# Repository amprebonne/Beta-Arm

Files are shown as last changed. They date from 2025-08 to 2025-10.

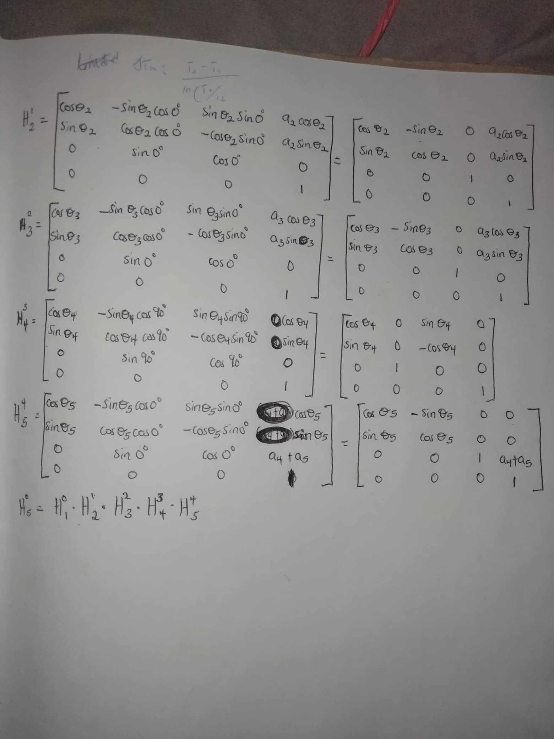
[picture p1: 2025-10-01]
mechanics/kinematics/maths/forward-kinematics-2.jpeg

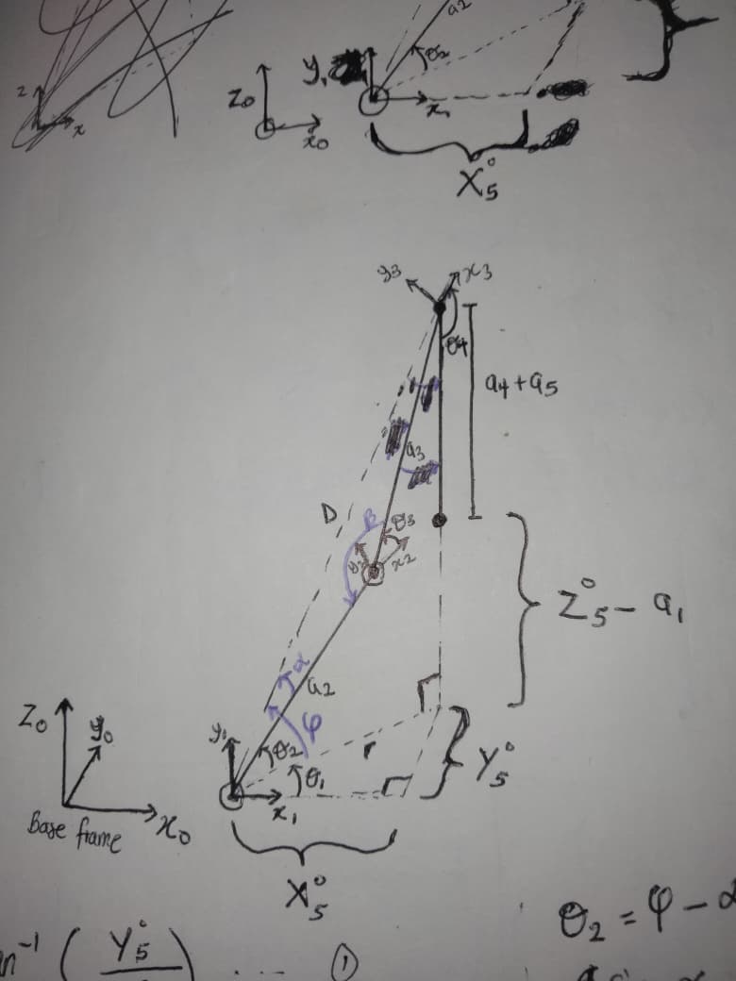
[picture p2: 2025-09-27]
mechanics/kinematics/maths/inverse-kinematics-note-1.jpeg

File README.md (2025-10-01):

# Overview
This repository contains the project files for a capstone project for MTR-362 Robotics, undertaken as part of an undergraduate mechatronics engineering program.
Our project aims to design, build, and demonstrate an intelligent pick-and-place robotic arm. The system integrates machine vision with real-time control to locate, identify, pick, and place selected objects efficiently overcoming the limitations of simple proximity sensor-based robotic arms.

# Objectives:
- Develop a cost-effective robotic arm with a modular design.
- Implement machine vision for precise object detection and localization.
- Achieve real-time multi-axis control using an STM32 microcontroller and G-code interface.
- Demonstrate pick-and-place tasks in a controlled environment.

# Key features
- Custom robotic arm with a gripper end effector.
- An embedded control system featuring an STM32 with Cortex M0 core for motion control.
- A camera module and a host PC for machine vision and object detection providing the MCU with coordinates of object location.

# Appendix: Project Files
This section contains links to all supplementary project files.
- **Project Presentation:** [View the slide deck on Google Slides](https://docs.google.com/presentation/d/1nX-H9TyuoCJQ-igmgSQgIlras0Ow6GI-e8l_YUqkpAM/edit?usp=sharing)
- **Final Project Report:** [Read the complete report](https://www.overleaf.com/3645491839kqrrjfkmpzjt#5574e6)
- **Manipulator kinematic diagrams:** [View the kinematic diagram drawing file](https://docs.google.com/drawings/d/15jNXW8rgt5O_UfLh6RkJmWEusIsC4YRsQ7lwjG3kFDY/edit?usp=sharing)
- **3D CAD Model:** [View the complete robotic arm assembly on Autodesk 3D Viewer](https://autode.sk/4nquLwD)

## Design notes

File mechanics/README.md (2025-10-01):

The robotic manipulator is a 5-DOF articulated arm composed of five revolute joints and corresponding links (\(a_{1}\)–\(a_{5}\)) that form its kinematic chain. Each joint provides a single rotational degree of freedom, enabling coordinated multi-axis motion suitable for basic pick-and-place tasks within a controlled workspace. A gripper end effector is mounted at the terminal link to handle lightweight objects, and the modular structure of the arm allows for easy mechanical adaptation and future extensions.

This directory contains all files related to the mechanical design of the Beta-Arm project. 
Mechanics focuses on the following:
- kinematics modeling & analysis
- mechanical CAD modeling with exports for 3-D printing
- updating the BOM - Bill of Materials with mechanical parts and expenses

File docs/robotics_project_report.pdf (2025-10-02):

# Design and Development of a 5-DOF Pick and Place

Manipulator.

October 2, 2025

## 1 Background

Robotic manipulators are widely used in automation for handling, assembly, and packaging. A 5-DOF arm offers full spatial control, allowing objects to be positioned and oriented flexibly. While industrial robots are effective, they are often costly and complex for small-scale use. Advances in microcontrollers, low-cost actuators, and 3D printing make it possible to build simpler, affordable manipulators. This project applies mechatronics principles to design a functional 6-DOF pick-and-place system as a practical educational prototype.

## 2 Aim

To design and develop a cost-effective 5-DOF robotic arm with a gripper that demonstrates accurate pick-and-place operations using affordable components.

## 3 Objectives

- To design a low-cost 5-DOF robotic arm with modular structure for easy adaptation.
- To implement real-time multi-axis control using an STM32 for precise motion.
- To integrate vision for object detection and demonstrate accurate pick-and-place.

## 4 Scope and Limitations

The project focuses on designing, fabricating, and testing a low-cost 5-DOF manipulator capable of performing basic pick-and-place tasks. The prototype is restricted to light payloads (< 500 g) and operates in a controlled environment with limited accuracy compared to industrial robots.

## 5 System Design Overview

The system consists of a custom-designed 5-DOF robotic arm with a gripper end effector, integrated with an embedded control system based on an STM32 microcontroller (Cortex-M0 core) for precise multi-axis motion. A camera module connected to a host PC provides machine vision capabilities, enabling object detection and localization. The vision system supplies the microcontroller with the coordinates of target objects, which are then used for pick-and-place operations. At the architectural level, the system can be described as a closed-loop mechatronic platform where sensing (camera), computation (PC and STM32), actuation (servo-driven joints), and end-effector manipulation (gripper) interact seamlessly. Functionally, the manipulator executes motion commands derived from G-code instructions while continuously receiving updated position data from the vision system. A block diagram representation of the architecture highlights these subsystems and the flow of information between them.

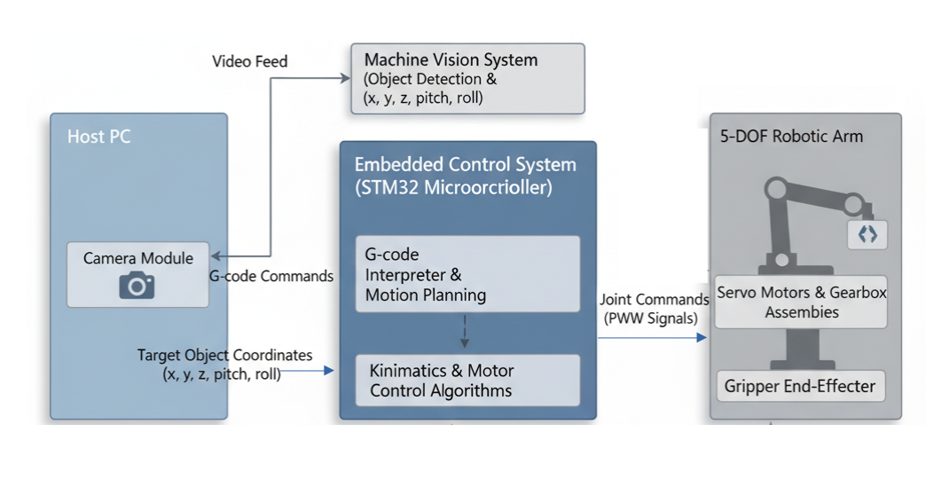
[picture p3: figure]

Figure 1: A block diagram of the Beta-Arm system

## 6 Mechanics

The robotic manipulator is a 5-DOF articulated arm composed of five revolute joints and corresponding links (a1–a5) that form its kinematic chain. Each joint provides a single rotational degree of freedom, enabling coordinated multi-axis motion suitable for basic pick-and-place tasks within a controlled workspace. A gripper end effector is mounted at the terminal link to handle lightweight objects, and the modular structure of the arm allows for easy mechanical adaptation and future extensions.

### 6.1 Kinematics

### 6.1.1 Forward Kinematics

The kinematic model of the manipulator was developed using the defined link lengths (a1–a5) and joint constraints. The structure was modeled in Autodesk Inventor to define geometry and assembly, while MATLAB was used to analyze workspace reach and validate joint limits. The resulting kinematic framework forms the foundation for subsequent motion planning and control.
The forward kinematics of the robotic manipulator involves systematically describing the relation-ship between consecutive links and joints in order to determine the position and orientation of the end-effector relative to the base frame. This process makes use of link parameters, joint definitions, rotational matrices, displacement vectors, and the Denavit–Hartenberg (D–H) convention, culminating in the construction of homogeneous transformation matrices.
1. Link Parameters: Define the physical dimensions of the manipulator, such as link lengths a1–a5, which form the kinematic chain:
a1 = 150.933 mm, | a2 = 128.914 mm, | a3 = 167.164 mm, | a4 = 50.056 mm, | a5 = 75.637 mm
2. Joint Limits: The manipulator consists of five revolute joints, each providing one degree of freedom (DOF). Each joint is constrained within the range:

T0, T1, T2, T3, T4 ∈ [−90◦

, 90◦
]
3. Rotational Matrices: Orientation between consecutive link frames is defined as:
| R
| 0 1 =
1 0 | 0
| 0 0 −1
0 1 | 0
- Ry, | R¹
| | 2 =
0 | 0 1
0 | 1 0
−1 0 0
| | | Rz,

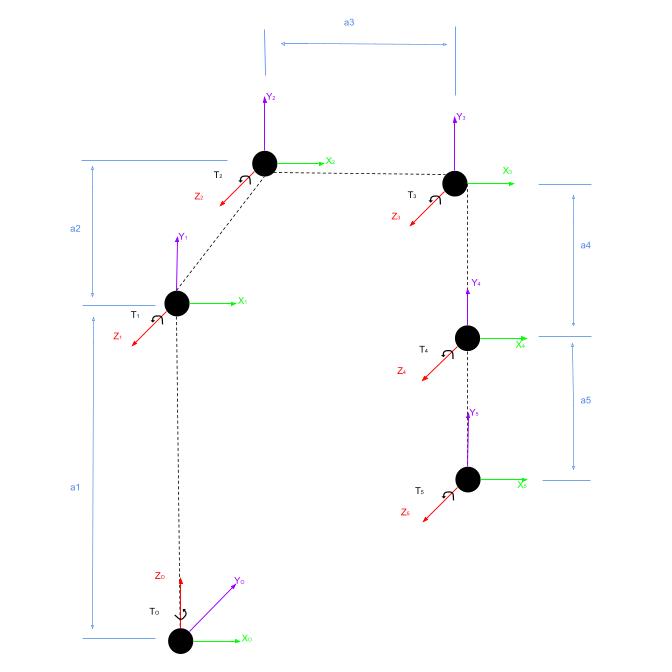
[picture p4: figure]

Figure 2: A kinematic diagram of the 5-DOF manipulator.

R

2
3 =
0 | 0 1
0 | 1 0
−1 0 0
- Rz, R³
4 =

1 0 0
0 0 −1
0 1 0
- Ry

R

4
5 =
1 | 0 | 0
0 | 0 | 1
0 −1 0
- Rz, R⁰
5 =
0 | 0 | 1
0 −1 0
1 | 0 | 0
- Rx
4. Displacement Vectors: Capture the relative translation between link frames, based on link offsets:

d

0
1 =

0
0
a1
- , d¹
2 =

a2
0
0
- , d²
3 =

a3
0
0
- , d³
4 =

a4
0
0
- , d⁴
5 =

0
0
a5
5. Denavit–Hartenberg Parameters in Tabular format: Summarizes all kinematic parameters (θi
, αi

, ai

, di) in a standardized form for the 5-DOF manipulator (see Table 1).

i | θi | αi | ai | di
1 | θ1 | 90◦ | 0 | a1
2 | θ2 | 0 | a2 | 0
3 | θ3 | 0 | a3 | 0
4 | θ4 | 90◦ | 0 | 0
5 | θ5 | 0 | 0 | a4 + a5

Table 1: Denavit–Hartenberg parameters for the robotic arm joints.

6. Homogeneous Transformation Matrices: Combine the rotational and translational effects into a single 4 × 4 matrix, enabling the computation of the end-effector pose by successive multiplications:

ci ≡ cos θi

, | si ≡ sin θi | (i = 1, . . . , 5).

0T1 =

c1 | −s1 cos 90◦
s1 sin 90◦ | 0 · c1
s1 | c1 cos 90◦ | −c1 sin 90◦ | 0 · s1
0 | sin 90◦
cos 90◦ | d1
0 | 0 | 0 | 1

=

c1 | 0 | s1 | 0
s1 | 0 −c1 | 0
0 | 1 | 0 | d1
0 | 0 | 0 | 1

,

where d1 = a1 (per table).

1T2 =

c2 | −s2 cos 0 | s2 sin 0 | a2c2
s2 | c2 cos 0 | −c2 sin 0 a2s2
0 | sin 0 | cos 0 | 0
0 | 0 | 0 | 1

=

c2 | −s2 | 0 a2c2
s2 | c2 | 0 a2s2
0 | 0 | 1 | 0
0 | 0 | 0 | 1

2T3 =

c3 | −s3 cos 0 | s3 sin 0 | a3c3
s3 | c3 cos 0 | −c3 sin 0 a3s3
0 | sin 0 | cos 0 | 0
0 | 0 | 0 | 1

=

c3 | −s3 | 0 a3c3
s3 | c3 | 0 a3s3
0 | 0 | 1 | 0
0 | 0 | 0 | 1

3T4 =

c4 | −s4 cos 90◦
s4 sin 90◦ | 0 · c4
s4 | c4 cos 90◦ | −c4 sin 90◦ | 0 · s4
0 | sin 90◦
cos 90◦ | 0
0 | 0 | 0 | 1

=

c4 | 0 | s4 | 0
s4 | 0 −c4 | 0
0 | 1 | 0 | 0
0 | 0 | 0 | 1

4T5 =

c5 | −s5 cos 0 | s5 sin 0 | 0 · c5
s5 | c5 cos 0 | −c5 sin 0 0 · s5
0 | sin 0 | cos 0 | d5
0 | 0 | 0 | 1

=

c5 | −s5 | 0 | 0
s5 | c5 | 0 | 0
0 | 0 | 1 d5
0 | 0 | 0 | 1

,

where d5 = a4 + a5 (per table).

0T5 =

0T1

1T2

2T3

3T4

4T5

0T5 =

"
R⁵
0 p

5
0
0

⊤ 1

, with R

5

0 = R1R2R3R4R5, p⁵ 0 = (resulting top-right 3×1 block after multiplication).

### 6.1.2 Inverse Kinematics

The inverse kinematics (IK) solution for the given 5-DOF serial manipulator is derived analytically using the Denavit-Hartenberg (DH) parameters. Assume the end-effector pose is specified by the

homogeneous transformation matrix 0T5 =

R p
0

⊤ 1

, where p = [px, py, pz]

⊤ is the position and

R = [rij ] (i, j = 1, 2, 3) is the rotation matrix. The solution proceeds in two stages: (1) solving for the first three joint angles θ1, θ2, θ3 to position the wrist center, and (2) solving for the last two angles θ4, θ5 to achieve the desired orientation. Two solutions may exist due to the elbow singularity (elbow-up/elbow-down configurations).

1. Computing the Wrist Center Position. The wrist center position pw = [pwx, pwy, pwz]

⊤ is
obtained by back-projecting from the end-effector along the approach vector (third column of R):
pwx = px − d5r13, | pwy = py − d5r23, | pwz = pz − d5r33, | (1)

where d5 = a4 + a5.

2. Solving for θ1 (Base Rotation). The first joint angle is determined from the projection in the xy-plane:
| θ1 = atan2(pwy, pwx), | | (2)

where atan2(y, x) is the two-argument arctangent function.
Let c1 = cos θ1 = √ pwx
p²

wx+p²
wy

and s1 = sin θ1 = √ pwy
| p² wx+p² wy .

The radial distance in the xy-plane is xc =

q
| p
| 2 wx + p
| 2 wy.
3. Solving for θ3 (Elbow Angle). Using the law of cosines in the shoulder-elbow-wrist triangle (with vertical offset z

′ = pwz − a1 and planar distance s =

p
| | x
| | 2 c + (z ′) 2):
cos θ3 = | x
| 2 c + (pwz − a1) 2 − a | 2 2 − a
| | 2
| | 3
| 2a2a3 | . | (3)

Then,
sin θ3 = ±

p
1 − cos² θ3, | (4)

yielding two possible solutions (positive for elbow-down, negative for elbow-up).

4. Solving for θ2 (Shoulder Angle). With θ3 known, define A = a2+a3 cos θ3 and B = a3 sin θ3. Then,
θ2 = atan2(z
| ′
, xc) − atan2(B, A), | (5)

where z

′ = pwz − a1.

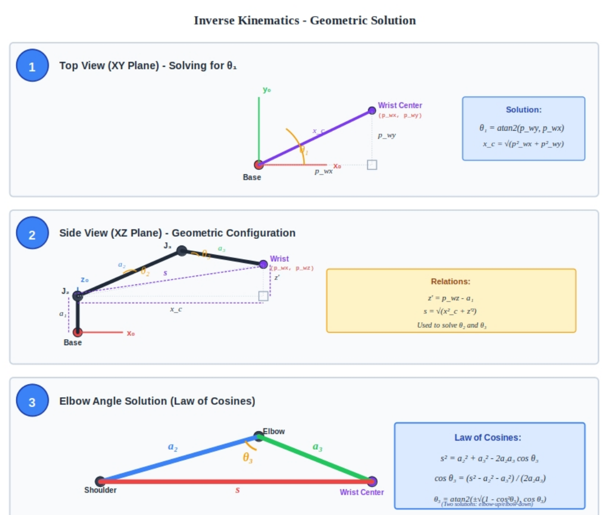
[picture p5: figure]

Figure 3: Inverse kinematic diagrams of the 5-DOF manipulator.

5. Orientation Consistency Check. Computing the columns of 0R3 (rotation matrix to frame
3) using the solved θ1, θ2, θ3:

u =

− sin θ2 sin θ3 cos θ1 + cos θ1 cos θ2 cos θ3 − sin θ1 sin θ2 sin θ3 + sin θ1 cos θ2 cos θ3 sin θ2 cos θ3 + sin θ3 cos θ2

- , v =

− sin θ2 cos θ1 cos θ3 − sin θ3 cos θ1 cos θ2 − sin θ1 sin θ2 cos θ3 − sin θ1 sin θ3 cos θ2 − sin θ2 sin θ3 + cos θ2 cos θ3

(6)
The second column of R must satisfy r·2 = [s1, −c1, 0]⊤ and r32 = 0 for a valid solution; otherwise, no real solution exists.
6. Solving for ϕ = θ4 + θ5 (Wrist Aggregate Angle). Using the third row of R:
ϕ = (θ2 + θ3) − atan2(r31, r33). | (7)
7. Solving for θ4 (Wrist Pitch). The approach vector n = [r13, r23, r33]

⊤ satisfies n = sin θ4 u − cos θ4 v. Thus,
sin θ4 = n
⊤u, | cos θ4 = −n
⊤v, | (8)

and
θ4 = atan2(n

⊤u, −n

⊤v). | (9)
8. Solving for θ5 (Wrist Roll). Finally,
θ5 = ϕ − θ4. | (10)

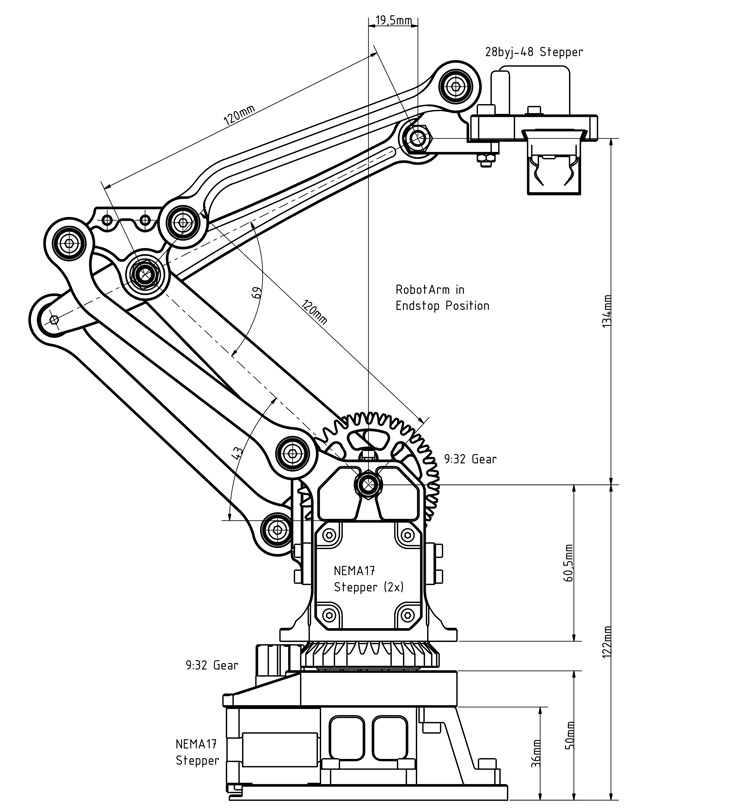
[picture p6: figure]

Figure 4: 2-D CAD drawing

### 6.2 Mechanical-CAD

The mechanical design phase of the Beta-Arm project harnessed Autodesk Inventor as the primary MCAD platform to conceptualize and refine a lightweight, 5-DOF serial robotic arm optimized for 3D printing and servo integration, transforming initial kinematic sketches into a fully assemblable prototype with minimal material waste and enhanced structural performance. The design workflow com-menced in Inventor’s part modeling environment, where over 25 individual components were meticu-lously crafted, including the robust base mount for stable platform attachment, the ergonomic shoulder bracket to distribute torque loads, segmented upper arm links for flexibility, intricate forearm elements to achieve the desired reach, a modular wrist assembly for precise orientation control, and duplicated 29-tooth spur gears to implement backlash-minimizing reduction ratios. Upon finalizing the virtual model, the export phase tailored outputs for downstream manufacturing, generating high-resolution .stl meshes.

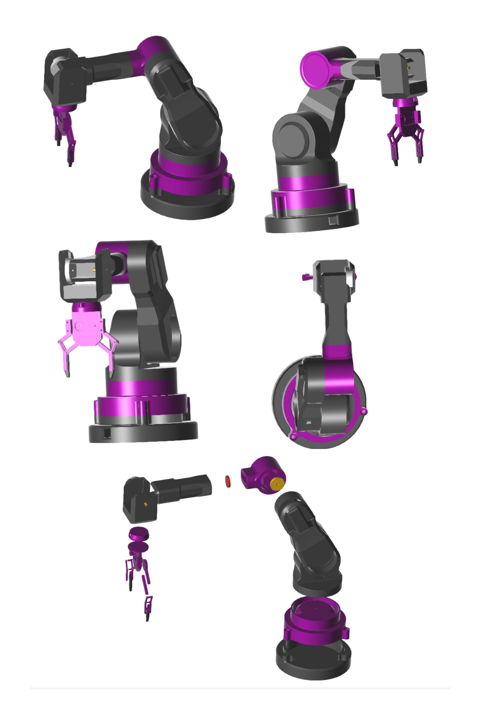
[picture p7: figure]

Figure 5: 3-D projections of the 5-DOF manipulator.

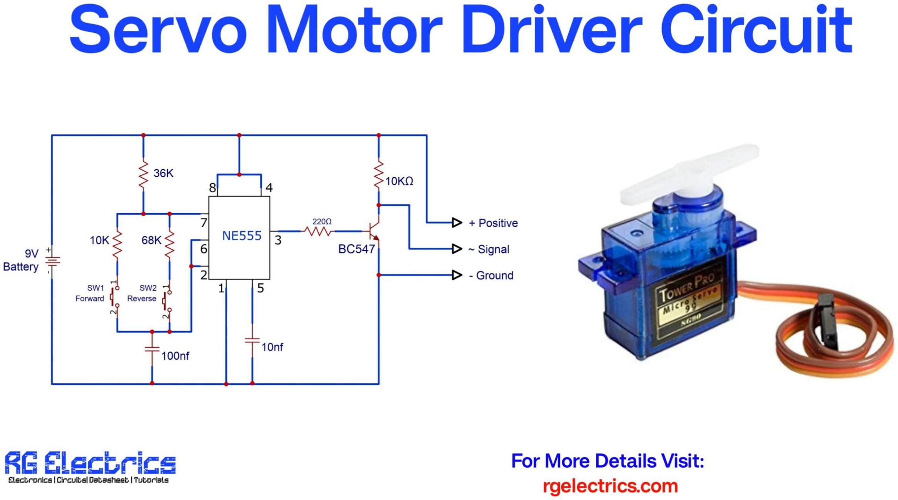
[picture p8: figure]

Figure 6: Circuit schematic

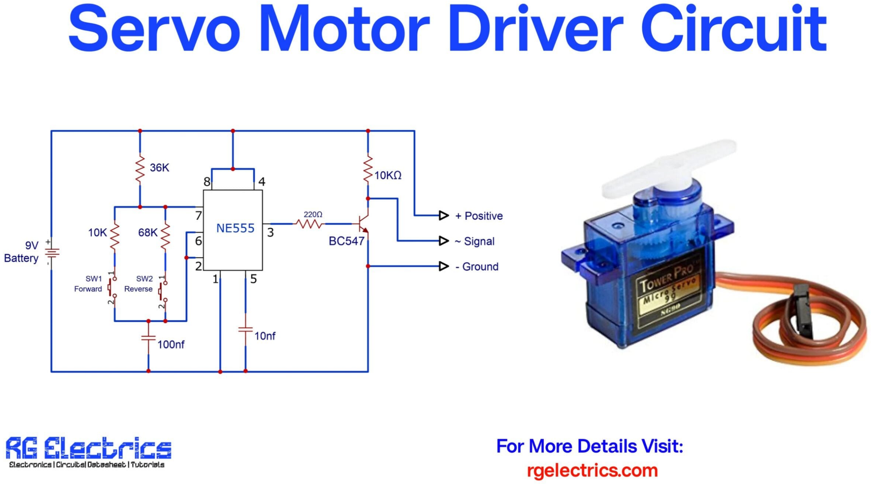
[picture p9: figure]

Figure 7: Circuit schematic

## 7 Electronics

The electronics subsystem of the Beta-Arm integrates low-cost, readily available components to enable precise servo actuation, embedded control, and computer vision integration. Key selections prioritize compatibility with the STM32 microcontroller, power efficiency, and scalability for future enhance-ments like wireless communication.

### 7.1 Circuit Design and Wiring

The circuit employs a modular breadboard layout to minimize soldering and facilitate prototyping. The STM32F030C6 interfaces with the PCA9685 via I²C (SDA/SCL pins) for PWM servo control, with five MG996R servos and one MG90 connected to channels 0–5, sharing a common 5 V rail from the power adapter. UART (TX/RX) on the STM32 links to the host PC for command reception from Python scripts, while the ESP32-CAM connects via USB or serial for image streaming to the host for YOLO processing. Power distribution uses the barrel jack to the breadboard rails.

### 7.2 Bill of Materials (BOM)

The BOM lists essential components, estimated costs, and quantities, totaling under $50 for core electronics.

Component | Qty | Specification
STM32F030C6 | 1 | 32 KB Flash, 4 KB SRAM, 48 MHz, LQFP-48
MG996R Servo | 5 | 11 kg·cm @ 6 V, 4.8–7.2 V, 0.17 s/60°
MG90 Servo | 1 | 2.2 kg·cm @ 4.8 V, 4.8–6 V, 0.1 s/60°
Power Adapter | 1 | 5 V, 3 A output
PCA9685 Driver | 1 | 16-ch PWM, 12-bit, I²C
ESP32-CAM Module | 1 | 1600×1200, Wi-Fi/BT, OV2640
DC Barrel Jack | 1 | 5.5/2.1 mm, 5–12 V
Jumper Cables | Assorted | M-M, M-F, F-F, 10 cm
Mini Breadboard | 1 | 170 tie-points, single rail

Table 2: Bill of Materials for Electronics Subsystem.

## 8 Controls and Software

### 8.1 Embedded Software (STM32F030R6)

The embedded software was developed on the STM32F030R6 microcontroller (ARM Cortex-M0 core) to handle servo actuation and communication with the host PC. The PCA9685 PWM driver was configured over I2C for precise servo control, while UART provided a serial interface for receiving object detection data from the host system.
Key functionalities implemented include:
- System clock configuration at 48 MHz for real-time control.
- I2C initialization for communication with the PCA9685 driver.
- Functions for setting individual, multiple, or all servo angles.
- UART initialization and communication routines for receiving YOLO object detection data.
- Parsing of bounding box coordinates into a format usable for robotic arm control.

Reference: controls-software/Stm32f030rct6/ (GitHub)
[language=C, caption=STM32 Embedded Code Snippet for Servo Control and UART Communication, basicstyle=]
void PCA9685Init(void)
PCA9685W riteReg(P CA9685MODE1, MODE1REST ART);
LLmDelay(10);
uint8tprescale = (uint8t)((OSCF REQ/(4096.0 ∗ SERV OF REQ)) + 0.5) − 1; uint8toldmode = P CA9685ReadReg(P CA9685MODE1);
uint8tnewmode = (oldmode MODE1REST ART)|MODE1SLEEP; PCA9685W riteReg(P CA9685MODE1, newmode);
PCA9685W riteReg(P CA9685P RESCALE, prescale);
PCA9685W riteReg(P CA9685MODE1, oldmode);
LLmDelay(5);
PCA9685W riteReg(P CA9685MODE1, oldmode|MODE1REST ART|MODE1AI); void PCA9685SetServoAngle(uint8tservo, uint16tangledeg)
uint16tpulse = 102 + ((angledeg ∗ 410)/180);
PCA9685SetPWM(servo, 0, pulse);
[language=C, caption=STM32 UART Parsing for YOLO Data, basicstyle=]
void ParseCoordinates(const char* data, int* centerx, int ∗ centery, int ∗ width, int ∗ height) *centerx = ∗centery = ∗width = ∗height = 0; chartempdata[100];
strncpy(tempdata, data, sizeof(tempdata) − 1);
tempdata[sizeof(tempdata) − 1] =′ ′;

char* token = strtok(tempdata, ”, ”); if (token) *centerx = atoi(token); token = strtok(NULL, ",");
if (token) *centery = atoi(token); token = strtok(NULL, ",");
if (token) *width = atoi(token); token = strtok(NULL, ",");
if (token) *height = atoi(token);

### 8.2 Machine Vision

The host PC implements object detection and vision-based control using the YOLOv8 deep learning model. The detected object coordinates (center position and bounding box dimensions) are sent to the STM32 over UART for real-time pick-and-place control.
Key functionalities implemented include:
- Live camera feed acquisition and preprocessing.
- YOLO inference for object detection and localization.
- Real-time visualization of bounding boxes and object centers.
- Serial communication of object coordinates to STM32.

Reference: controls-software/Python Scripts/ (GitHub)
[language=Python, caption=YOLO Object Detection with STM32 Communication, basicstyle=]
model = YOLO(’yolov8n.pt’)
cap = cv2.VideoCapture(1)
cap.set(3, 1280)
cap.set(4, 720)
while True:
success, img = cap.read()
if not success: continue
results = model(img, verbose=False)
for box, cls in zip(results[0].boxes.xyxy.cpu().numpy(), results[0].boxes.cls.cpu().numpy()):
x1, y1, x2, y2 = box.astype(int)
centerx, centery = (x1 + x2)//2,(y1 + y2)//2
width, height = x2 - x1, y2 - y1
cv2.rectangle(img, (x1, y1), (x2, y2), (0,255,0), 2) cv2.circle(img, (centerx, centery), 5,(0, 0, 255), −1) classname = model.names[int(cls)]
cv2.putText(img, classname,(x1, y1 − 10), cv2.FONTHERSHEYSIMP LEX, 0.5,(0, 255, 0), 2) message = f"centerx, centery, width, height˚”

ser.write(message.encode(’utf-8’)) ser.flush()

## 9 Fabrication and Assembly

The manipulator arm was realized through 3D printing of all required links and joints. STL files were first exported and prepared for slicing, after which the parts were printed on an Ender 3 using PLA filament. Once printed, the components were inspected to ensure dimensional accuracy and assembled into the complete manipulator arm without major fitting issues. Parts were assembled without much difficulty.
The manipulator base platform was fabricated from ABS board to provide a stable mounting surface for the arm. A 24 in × 24 in square grid was designed and then pasted onto the ABS board. This ensured accurate placement of the arm and alignment with the workspace. The base platform was successfully made from ABS board and 24×24 inch SAV grid sheets.

The electronic subsystem was developed on a modular breadboard layout to simplify prototyping and reduce soldering. The STM32F030C6 microcontroller interfaced with the PCA9685 driver over I

2C, generating PWM signals for five MG996R servos and one MG90 connected on channels 0–5. All servos shared a regulated 5 V supply distributed across the breadboard rails from a barrel-jack adapter. UART lines on the STM32 were connected to the host PC for command reception from Python scripts, while the ESP32-CAM was connected via USB/serial to provide real-time image streaming for YOLO-based object detection. The integration process involved validating PWM outputs, testing servo response, and checking communication links between the STM32, ESP32-CAM, and PC. The system performed reliably after assembly, with synchronized mechanical actuation and visual feedback confirmed in the gallery records. The circuit was assembled on a breadboard, tested with the PCA9685 and servos, and verified to interface correctly with both the STM32 and ESP32-CAM modules. All subsystems operated as intended.

## 10 Results and Analysis

The manipulator was first subjected to motion tests to verify smooth operation across all joints. Individual servos were actuated and then driven in coordinated sequences to evaluate overall range of motion and responsiveness. These trials confirmed that the PCA9685 driver, controlled through the STM32, produced stable PWM signals that resulted in consistent actuation. Videos of these sequences, including pick-and-place demonstrations, were recorded and archived in the project gallery. Payload capacity was then evaluated by gradually increasing the weight lifted at the gripper. The arm handled lightweight objects reliably, though higher loads highlighted servo torque limitations that constrained the maximum payload which was less than 500 grams.
Accuracy and repeatability were assessed by commanding the manipulator to reach predefined target points on the base platform grid. Measurements showed that the end-effector could consistently reach within a few millimeters of the desired location, with repeat trials producing similar results. However, small deviations were observed due to servo backlash and tolerances in the 3D-printed joints. Overall, the system demonstrated stable motion, adequate payload capacity for its intended use, and reasonable accuracy for an educational and demonstrative robotic manipulator.

## 11 Conclusions and Recommendations

The development of the robotic manipulator successfully demonstrated the integration of embedded control, machine vision, and low-cost fabrication methods. The system achieved smooth joint actuation through the STM32 and PCA9685 driver, with vision-based control enabled by YOLO detection on the host PC. Fabrication using 3D-printed parts and an ABS board platform provided a cost-effective and modular assembly, while circuit prototyping on a breadboard allowed rapid iteration. Motion tests confirmed reliable operation, payload trials showed adequate lifting for lightweight objects, and accuracy tests indicated reasonable repeatability for educational and demonstrative use. Overall, the project achieved its design objectives within the given constraints.
For future improvements, several recommendations are proposed. Mechanical precision can be enhanced by refining 3D-printed joints or introducing metal reinforcements to reduce backlash. Replacing the breadboard layout with a custom PCB would improve reliability and wiring robustness. Higher torque servos or closed-loop actuators could extend payload capacity, while implementing kinematic calibration would improve positioning accuracy. Finally, integrating onboard vision processing directly on an ESP32 or Jetson Nano could reduce latency and enable more autonomous operation. These en-hancements would allow the system to scale from a prototype demonstrator to a more capable robotic platform.

## A Project repository

https://github@@.com/amprebonne/Beta-Arm

## B 3D-MCAD Assembly

https://autode.sk/4nquLwD

## C Gallery

https://github@@.com/amprebonne/Beta-Arm/tree/main/gallery

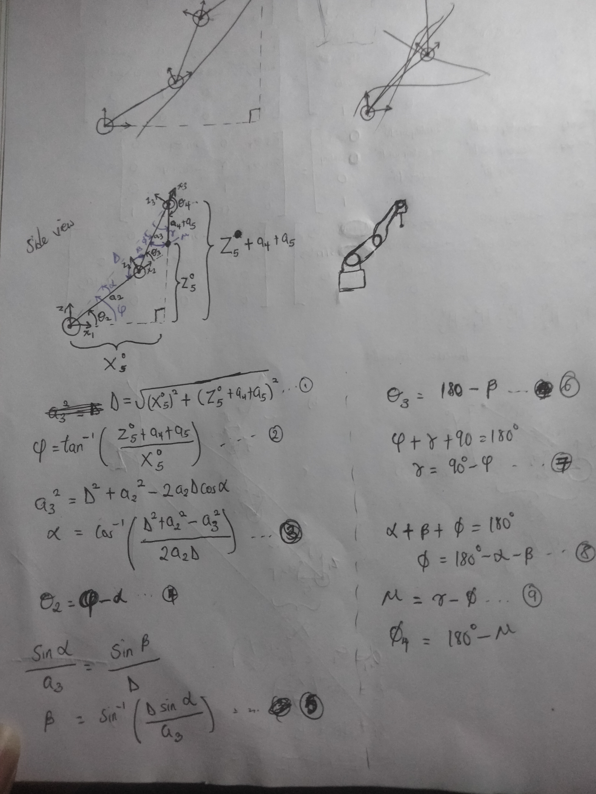
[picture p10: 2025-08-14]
mechanics/kinematics/maths/inverse-kinematics-note-2.jpg

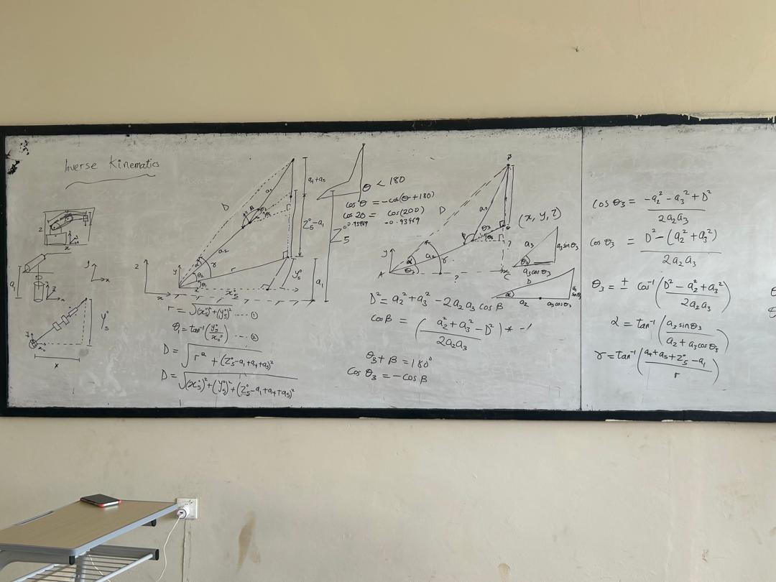
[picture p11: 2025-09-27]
mechanics/kinematics/maths/inverse-kinematics-whiteboarding-2.jpeg

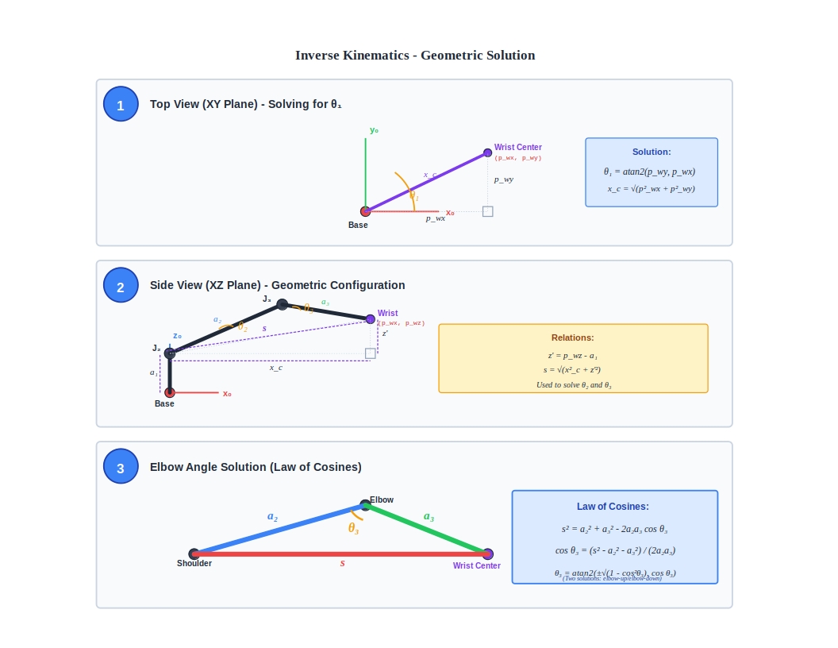
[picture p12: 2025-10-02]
gallery/inverse_kinematics_diagram.jpg

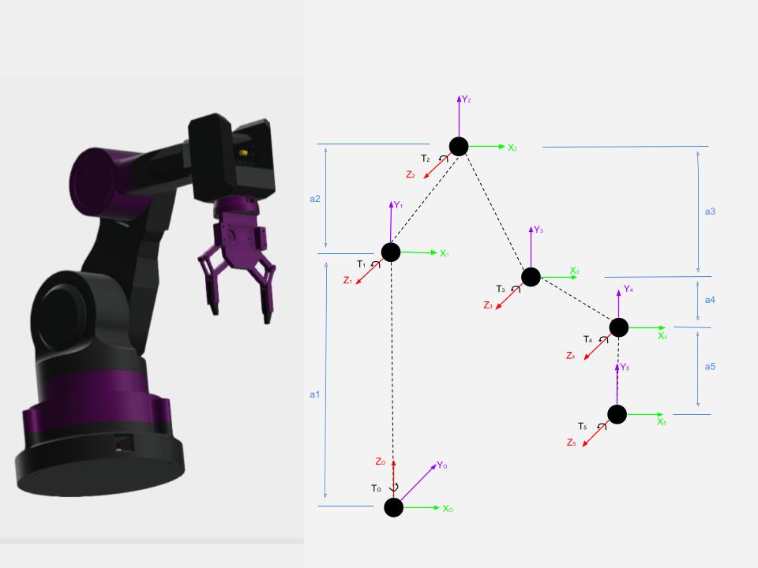
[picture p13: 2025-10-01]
mechanics/kinematics/maths/kinematic-diagram-1.jpg

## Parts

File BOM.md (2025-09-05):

STM32F030C6 → 32 KB Flash, 4 KB SRAM, 48 MHz, LQFP-48

MG996R servos (5) – 11 kg·cm torque @ 6 V, operating voltage 4.8–7.2 V, 0.17 s/60° speed

MG90 servo (1) – 2.2 kg·cm torque @ 4.8 V, operating voltage 4.8–6 V, 0.1 s/60° speed

Power adapter (1) – 5 V, 3 A output

Servo motor driver (1) – 16-channel PWM driver (e.g., PCA9685, 12-bit resolution, I²C interface)

ESP32 camera module (1) – ESP32-CAM, 1600 × 1200 image capture, Wi-Fi + Bluetooth, OV2640 camera sensor

Male power jack supply (1) – DC barrel connector, 5.5 mm outer / 2.1 mm inner diameter, rated 5 V–12 V

Jumper cables – Assorted male-to-male, male-to-female, female-to-female, ~10 cm length

Breadboard (1) – Mini type, ~170 tie-points, single power rail

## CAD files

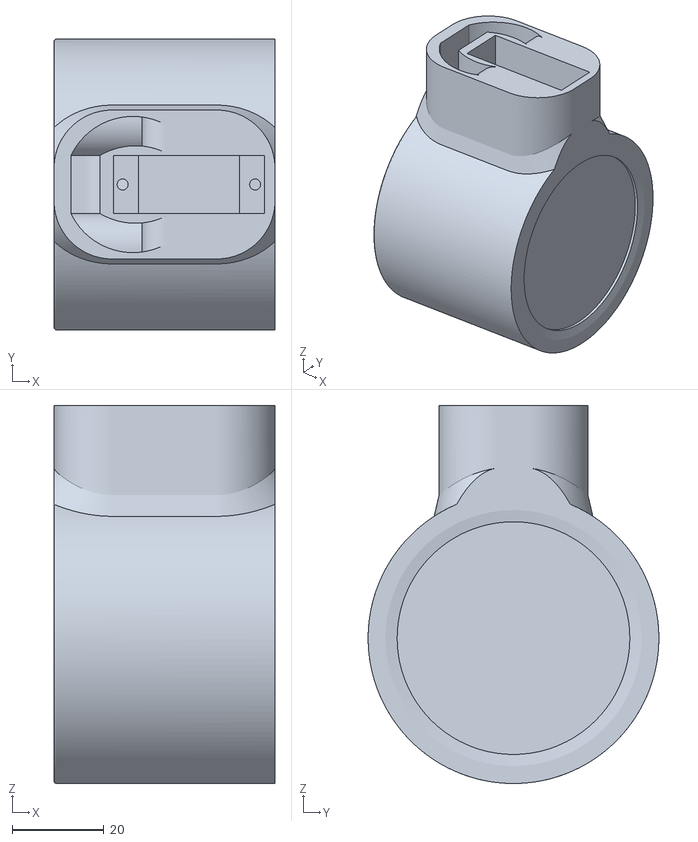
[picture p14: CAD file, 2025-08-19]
fab/arm/3D-printfiles/Assembly 1 - Part 3 - Part 1.stl
48.3 x 63.5 x 82.6

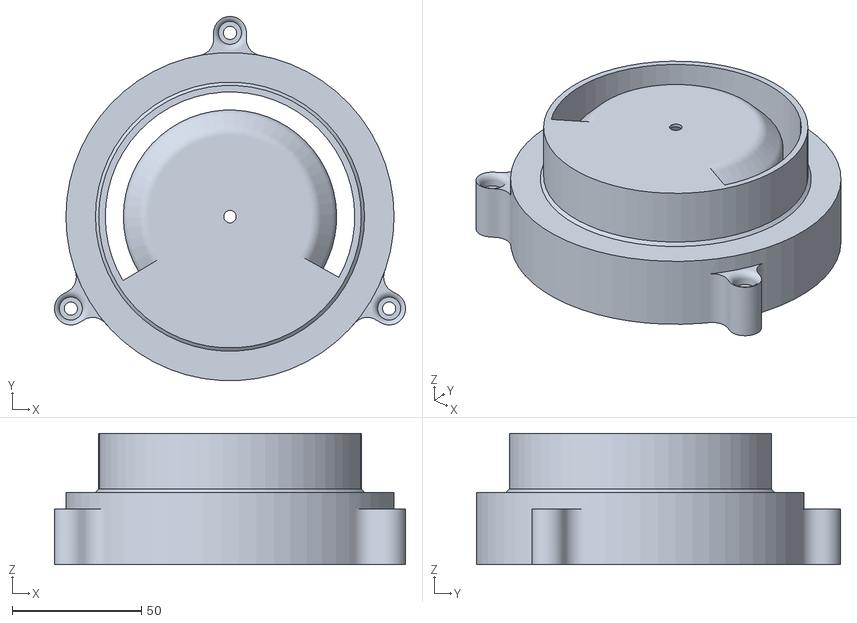
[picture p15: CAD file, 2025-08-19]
fab/arm/3D-printfiles/Assembly 1 - Part 1 - Part 1.stl
135.9 x 140.9 x 50.8

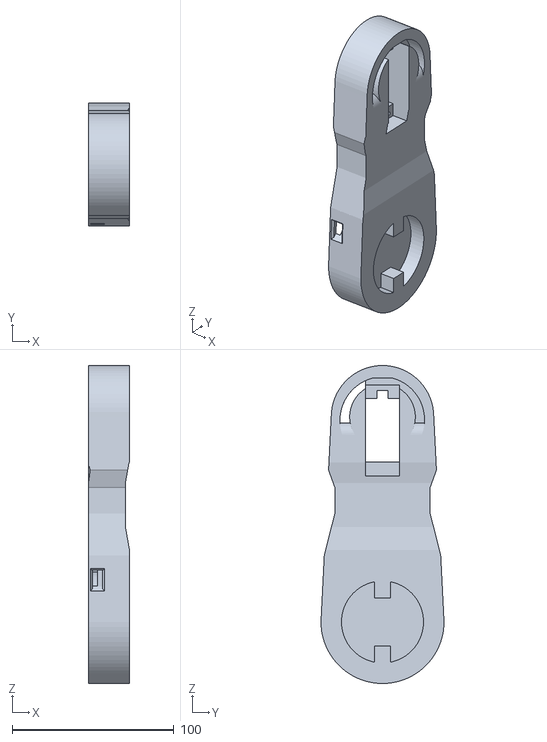
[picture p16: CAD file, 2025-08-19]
fab/arm/3D-printfiles/Assembly 1 - Part 10.stl
25.4 x 76.2 x 196.9

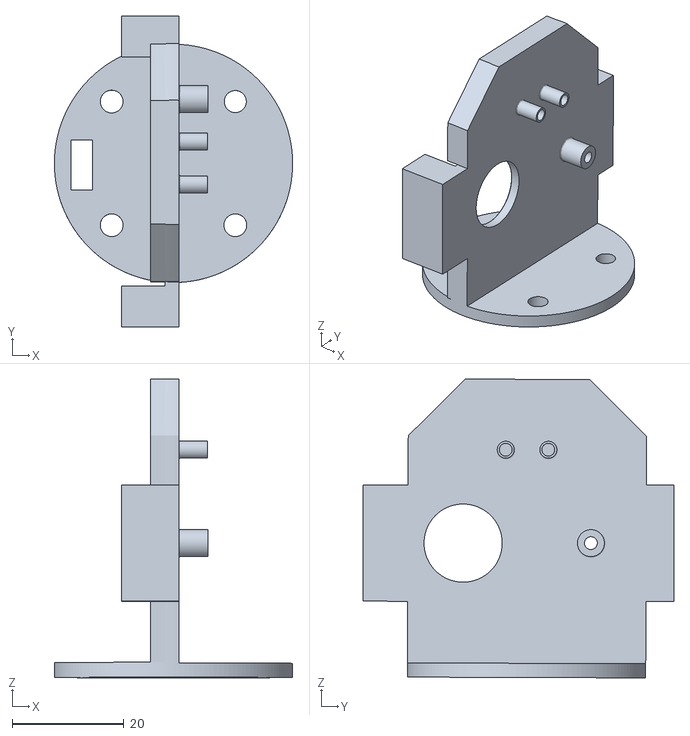
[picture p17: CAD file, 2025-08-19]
fab/arm/3D-printfiles/Assembly 1 - Part 52 - Part 1.stl
42.6 x 55.6 x 53.5

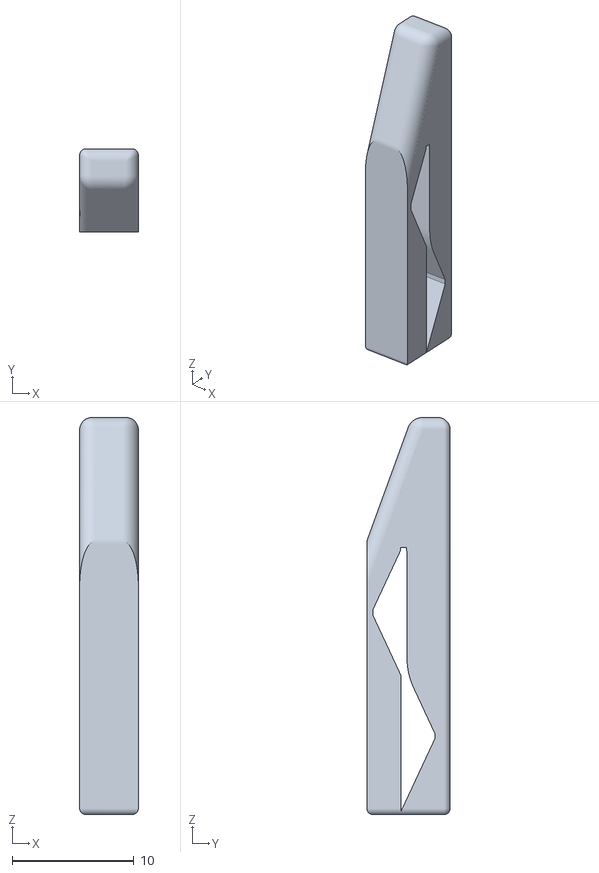
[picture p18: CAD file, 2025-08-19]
fab/arm/3D-printfiles/Assembly 1 - Part 62 - Part 1.stl
4.83 x 6.86 x 32.6

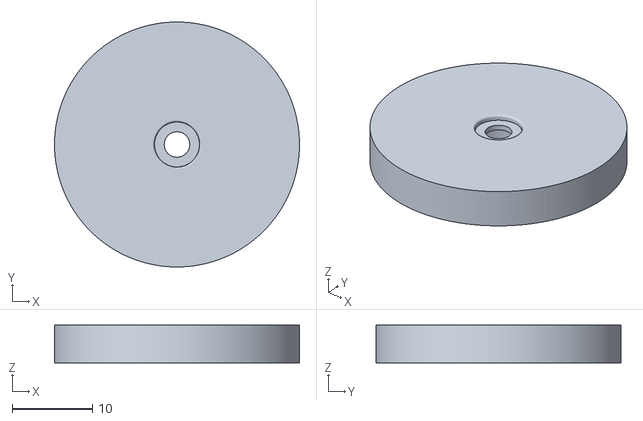
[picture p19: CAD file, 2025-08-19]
fab/arm/3D-printfiles/Assembly 1 - Part 15 - Part 1.stl
30.5 x 30.5 x 4.70

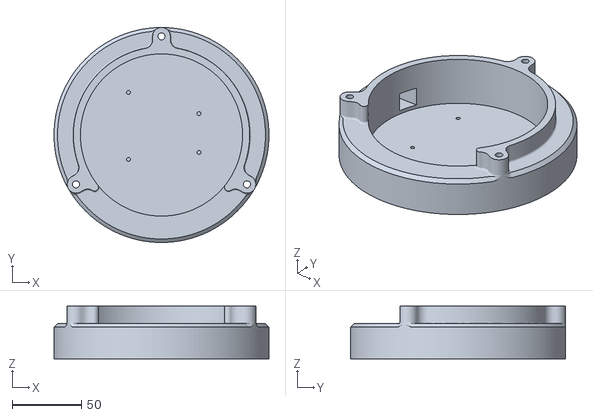
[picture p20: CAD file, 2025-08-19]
fab/arm/3D-printfiles/Assembly 1 - Part 18 - Part 1.stl
154.9 x 154.9 x 38.1

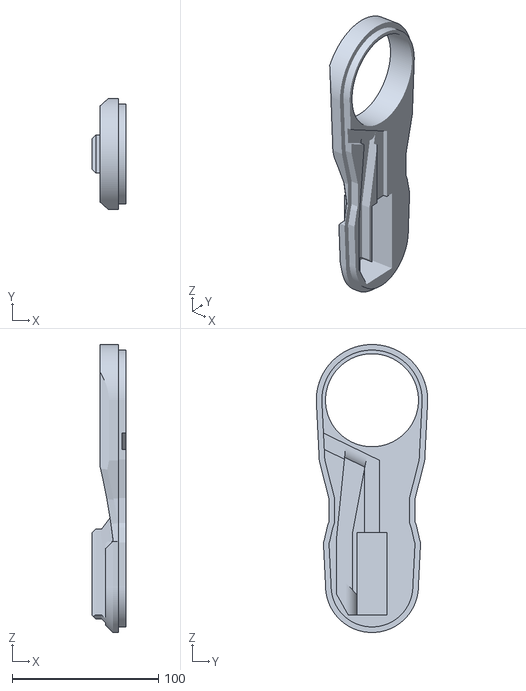
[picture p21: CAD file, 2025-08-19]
fab/arm/3D-printfiles/Assembly 1 - Part 11_MIR - Part 1.stl
23.0 x 76.2 x 196.8

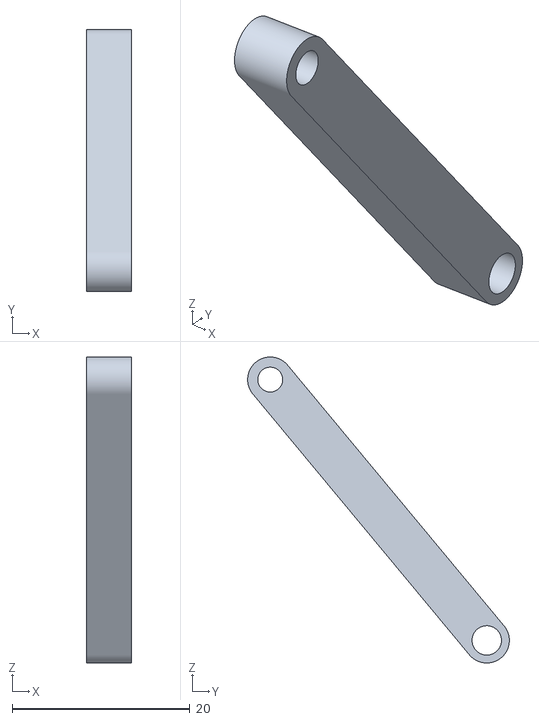
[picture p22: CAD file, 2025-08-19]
fab/arm/3D-printfiles/Assembly 1 - Part 56 - Part 1.stl
5.08 x 29.4 x 34.4

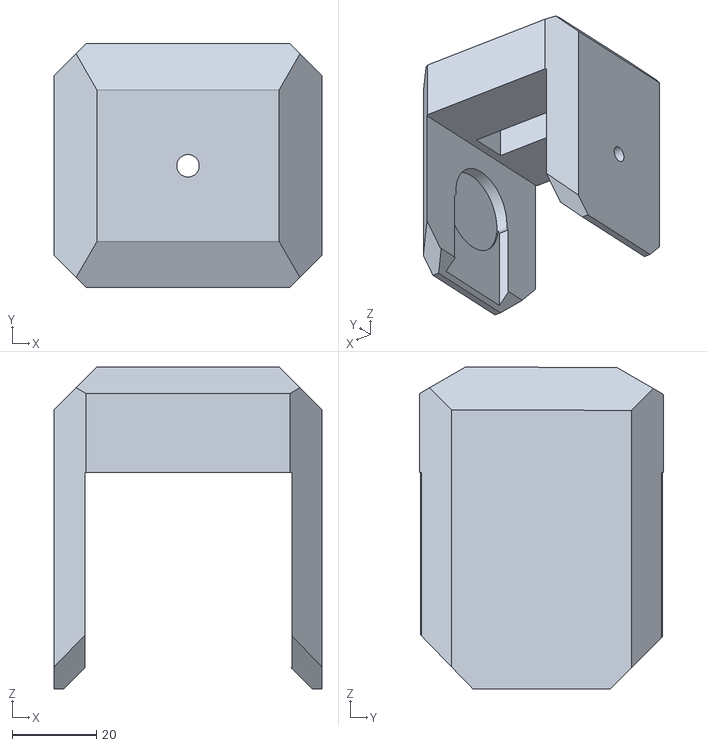
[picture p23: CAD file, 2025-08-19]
fab/arm/3D-printfiles/Assembly 1 - Part 6 - Part 1.stl
63.5 x 57.9 x 76.4

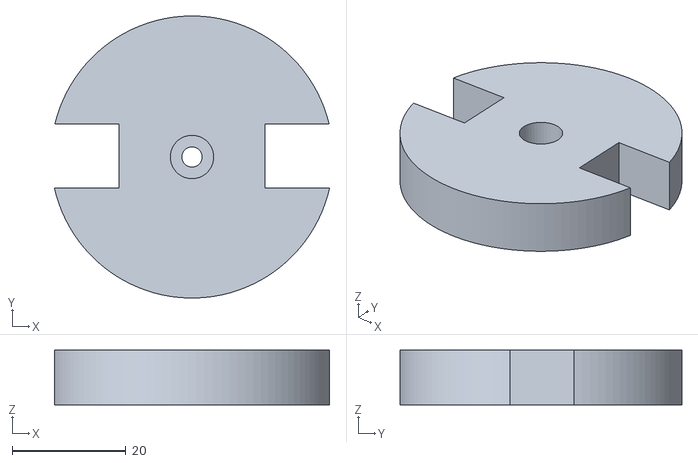
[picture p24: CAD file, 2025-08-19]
fab/arm/3D-printfiles/Assembly 1 - Part 16.stl
48.3 x 49.5 x 9.65

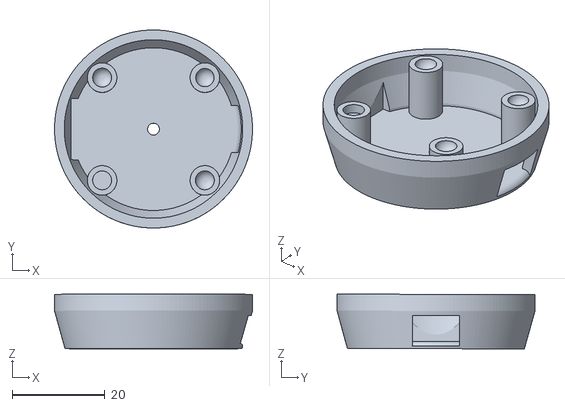
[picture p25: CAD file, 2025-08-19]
fab/arm/3D-printfiles/Assembly 1 - Part 14 - Part 1.stl
42.6 x 42.6 x 11.8

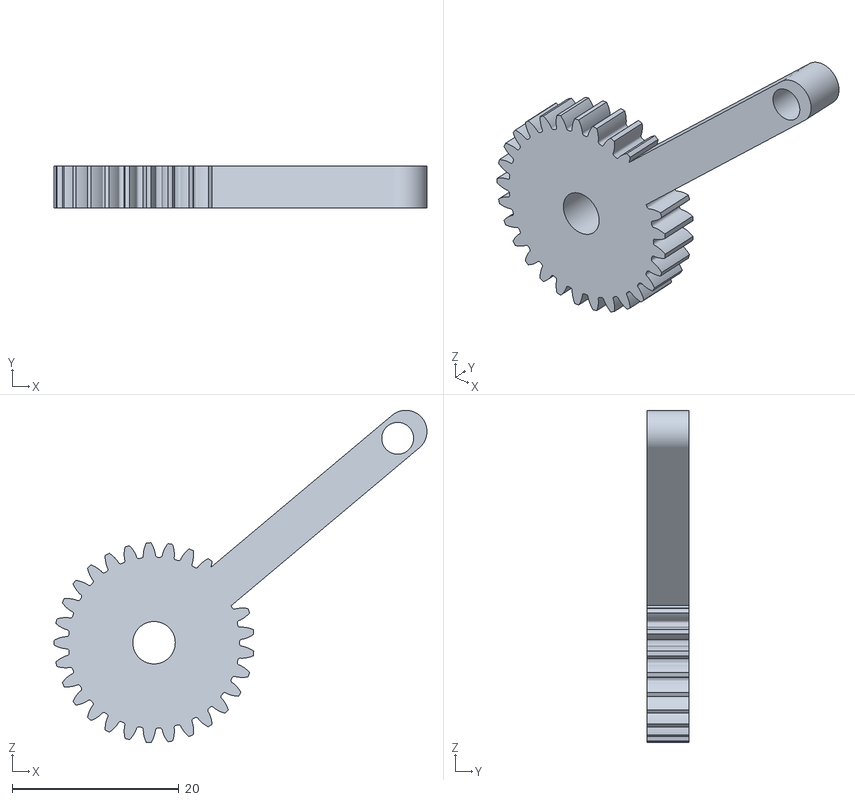
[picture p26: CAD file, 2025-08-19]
fab/arm/3D-printfiles/Assembly 1 - Spur gear (29 teeth) (1) - Part 1.stl
44.7 x 5.08 x 39.8

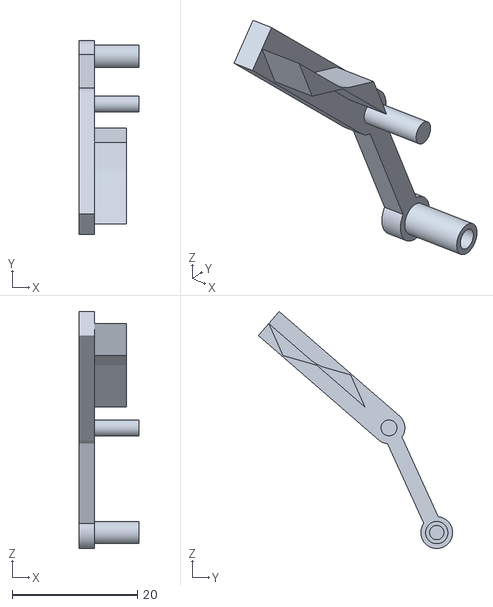
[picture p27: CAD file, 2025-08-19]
fab/arm/3D-printfiles/Assembly 1 - Part 57 - Part 1.stl
9.65 x 31.0 x 37.8

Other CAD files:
fab/arm/3D-printfiles/Assembly 1 - Part 55 - Part 1.stl
fab/arm/3D-printfiles/Assembly 1 - Part 19.stl
fab/arm/3D-printfiles/Assembly 1 - Part 2.stl
fab/arm/3D-printfiles/Assembly 1 - Part 58 - Part 1.stl
fab/arm/3D-printfiles/Assembly 1 - Part 4 - Part 1.stl
fab/arm/3D-printfiles/Assembly 1 - Part 59 - Part 1.stl
fab/arm/3D-printfiles/Assembly 1 - Part 6 (1) - Part 1.stl
fab/arm/3D-printfiles/Assembly 1 - Part 61 - Part 1.stl
fab/arm/3D-printfiles/Assembly 1 - Part 63 - Part 1.stl
fab/arm/3D-printfiles/Assembly 1 - Spur gear (29 teeth) - Part 1.stl
mechanics/CAD/inventor-exports/Assembly 1 - Part 1/Assembly 1 - Part 1.ipt
mechanics/CAD/inventor-exports/Assembly 1 - Part 1/OldVersions/Assembly 1 - Part 1.0002.ipt
mechanics/CAD/inventor-exports/Assembly 1 - Part 10/Assembly 1 - Part 10.ipt
mechanics/CAD/inventor-exports/Assembly 1 - Part 10/OldVersions/Assembly 1 - Part 10.0001.ipt
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

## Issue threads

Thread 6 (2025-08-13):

Fabrication - 3D printing

AurelixML, 2025-08-13:
**Task:**
- Export .stl files for printing
- Ensure all parts are 3D printed and functional.

**Deliverables:**
- Upload .stl files to Beta-Arm/fab/printfiles
- Upload image of each printed part to Beta-Arm/fab/3D-prints

Closed 2025-09-05.

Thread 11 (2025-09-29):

base platform

amprebonne, 2025-09-29:
Task:
- Make platform base from wood, perspex, PVC or ABS board material.
- Design grid and export printables in pdf format.
- Print grid sheet and paste on wooden base surface.

Deliverables:
- Base grid printfile - /fab/platform
- Base grid fabrication assembly - /gallery

Closed 2025-09-29.

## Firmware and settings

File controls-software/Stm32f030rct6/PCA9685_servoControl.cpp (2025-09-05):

#include "stm32f0xx_ll_rcc.h"
#include "stm32f0xx_ll_system.h"
#include "stm32f0xx_ll_utils.h"
#include "stm32f0xx_ll_gpio.h"
#include "stm32f0xx_ll_i2c.h"
#include "stm32f0xx_ll_bus.h"



// PCA9685 Register Addresses
#define PCA9685_MODE1       0x00
#define PCA9685_PRESCALE    0xFE
#define PCA9685_LED0_ON_L   0x06
#define PCA9685_LED0_ON_H   0x07
#define PCA9685_LED0_OFF_L  0x08
#define PCA9685_LED0_OFF_H  0x09

// PCA9685 Mode bits
#define MODE1_RESTART       0x80
#define MODE1_SLEEP         0x10
#define MODE1_AI            0x20

// Configuration
#define PCA9685_I2C_ADDR    0x40        // 7-bit address
#define SERVO_FREQ          50          // 50Hz for standard servos
#define OSC_FREQ            25000000    // Internal oscillator frequency

// Function prototypes
void SystemClock_Config(void);
void I2C1_Init(void);
void PCA9685_Init(void);
void PCA9685_SetServoAngle(uint8_t servo, uint16_t angle_deg);
void PCA9685_SetAllServos(uint16_t angle_deg);
void PCA9685_SetMultipleServos(uint16_t angles[6]);
void PCA9685_SetPWM(uint8_t servo, uint16_t on, uint16_t off);
void PCA9685_WriteReg(uint8_t reg, uint8_t value);
uint8_t PCA9685_ReadReg(uint8_t reg);

int main(void)
 {
    SystemClock_Config();
     LL_Init1msTick(48000000);
    I2C1_Init();
    
    // Initialize PCA9685
    PCA9685_Init();
    
    
    while (1)
    {
        
    //    while(1){
    //    for (float angle = 100; angle <= 180; angle +=10) {
    //    PCA9685_SetServoAngle(0, angle);
    //    LL_mDelay(100); // Wait 500ms between steps - using wait_ms() for your library
    //    // wait_ms(500); // Alternative using your library's wait_ms function
    //  }
    
    //for (float angle = 180; angle >= 100; angle -= 10) {
    //    PCA9685_SetServoAngle(0, angle);
    //    LL_mDelay(100);
    //}
    //LL_mDelay(5000);
    //}
        //PCA9685_SetServoAngle(0, 150);  // Move servo to 90°
        LL_mDelay(300000);  // Stagger the movement
        // Example 1: Control all 6 servos to same position
        PCA9685_SetAllServos(0);    // All to 0°
        LL_mDelay(1000);
        
        
        // Example 2: Control each servo individually
        for(uint8_t servo = 0; servo < 6; servo++)
        {
            PCA9685_SetServoAngle(servo, 90);  // Move servo to 90°
            LL_mDelay(300);  // Stagger the movement
        }
        LL_mDelay(1000);
        
        // Example 3: Set all servos to different positions at once
        uint16_t positions[6] = {0, 30, 60, 90, 120, 180};  // Different angles
        PCA9685_SetMultipleServos(positions);
        LL_mDelay(2000);
        
        // Example 4: Wave pattern
        for(uint16_t angle = 0; angle <= 180; angle += 10)
        {
            for(uint8_t servo = 0; servo < 6; servo++)
            {
                uint16_t servo_angle = angle + (servo * 15);  // Offset each servo
                if(servo_angle > 180) servo_angle = 180;
                PCA9685_SetServoAngle(servo, servo_angle);
            }
            LL_mDelay(100);
        }
        
        LL_mDelay(2000);
    }
}

void PCA9685_Init(void)
{
    // Reset the PCA9685
    PCA9685_WriteReg(PCA9685_MODE1, MODE1_RESTART);
    LL_mDelay(10);
    
    // Set PWM frequency to 50Hz for servo control
    // Calculate prescale: prescale = (OSC_FREQ / (4096 * freq)) - 1
    uint8_t prescale = (uint8_t)((OSC_FREQ / (4096.0 * SERVO_FREQ)) + 0.5) - 1;
    
    // Put PCA9685 to sleep to set prescale
    uint8_t oldmode = PCA9685_ReadReg(PCA9685_MODE1);
    uint8_t newmode = (oldmode & ~MODE1_RESTART) | MODE1_SLEEP;
    PCA9685_WriteReg(PCA9685_MODE1, newmode);
    
    // Set prescale
    PCA9685_WriteReg(PCA9685_PRESCALE, prescale);
    
    // Wake up and enable auto-increment
    PCA9685_WriteReg(PCA9685_MODE1, oldmode);
    LL_mDelay(5);
    PCA9685_WriteReg(PCA9685_MODE1, oldmode | MODE1_RESTART | MODE1_AI);
}

void PCA9685_SetServoAngle(uint8_t servo, uint16_t angle_deg)
{
    // MG996R extended range: 1ms to 2.5ms for 0° to 180°
    // At 50Hz: 20ms period = 4096 counts
    // 1ms = 204.8 counts ≈ 205
    // 2.5ms = 512 counts
    uint16_t pulse = 102 + ((angle_deg * 410) / 180);  // 0.5ms to 2.5ms range
    
    PCA9685_SetPWM(servo, 0, pulse);
}

void PCA9685_SetPWM(uint8_t servo, uint16_t on, uint16_t off)
{
    uint8_t reg = PCA9685_LED0_ON_L + 4 * servo;
    
    PCA9685_WriteReg(reg,     on & 0xFF);        // ON_L
    PCA9685_WriteReg(reg + 1, on >> 8);          // ON_H
    PCA9685_WriteReg(reg + 2, off & 0xFF);       // OFF_L
    PCA9685_WriteReg(reg + 3, off >> 8);         // OFF_H
}

void PCA9685_WriteReg(uint8_t reg, uint8_t value)
{
    // Wait until I2C is ready
    while(LL_I2C_IsActiveFlag_BUSY(I2C1));
    
    // Start I2C transaction
    LL_I2C_HandleTransfer(I2C1, PCA9685_I2C_ADDR << 1, LL_I2C_ADDRSLAVE_7BIT, 2, 
                         LL_I2C_MODE_AUTOEND, LL_I2C_GENERATE_START_WRITE);
    
    // Send register address
    while(!LL_I2C_IsActiveFlag_TXIS(I2C1));
    LL_I2C_TransmitData8(I2C1, reg);
    
    // Send data
    while(!LL_I2C_IsActiveFlag_TXIS(I2C1));
    LL_I2C_TransmitData8(I2C1, value);
    
    // Wait for transfer complete
    while(!LL_I2C_IsActiveFlag_STOP(I2C1));
    LL_I2C_ClearFlag_STOP(I2C1);
}

uint8_t PCA9685_ReadReg(uint8_t reg)
{
    uint8_t data;
    
    // Wait until I2C is ready
    while(LL_I2C_IsActiveFlag_BUSY(I2C1));
    
    // Send register address
    LL_I2C_HandleTransfer(I2C1, PCA9685_I2C_ADDR << 1, LL_I2C_ADDRSLAVE_7BIT, 1, 
                         LL_I2C_MODE_SOFTEND, LL_I2C_GENERATE_START_WRITE);
    
    while(!LL_I2C_IsActiveFlag_TXIS(I2C1));
    LL_I2C_TransmitData8(I2C1, reg);
    
    while(!LL_I2C_IsActiveFlag_TC(I2C1));
    
    // Read data
    LL_I2C_HandleTransfer(I2C1, PCA9685_I2C_ADDR << 1, LL_I2C_ADDRSLAVE_7BIT, 1, 
                         LL_I2C_MODE_AUTOEND, LL_I2C_GENERATE_START_READ);
    
    while(!LL_I2C_IsActiveFlag_RXNE(I2C1));
    data = LL_I2C_ReceiveData8(I2C1);
    
    while(!LL_I2C_IsActiveFlag_STOP(I2C1));
    LL_I2C_ClearFlag_STOP(I2C1);
    
    return data;
}

void SystemClock_Config(void)
{
    // Configure HSI as system clock source (8MHz)
    LL_RCC_HSI_Enable();
    while(!LL_RCC_HSI_IsReady());
    
    // Alternative: Direct register configuration if LL functions don't work
    // Configure PLL: HSI/2 * 12 = 48MHz
    RCC->CFGR &= ~(RCC_CFGR_PLLSRC | RCC_CFGR_PLLMUL);
    RCC->CFGR |= (RCC_CFGR_PLLSRC_HSI_DIV2 | RCC_CFGR_PLLMUL12);
    
    LL_RCC_PLL_Enable();
    while(!LL_RCC_PLL_IsReady());
    
    // Set flash latency
    LL_FLASH_SetLatency(LL_FLASH_LATENCY_1);
    
    // Configure system clock
    LL_RCC_SetSysClkSource(LL_RCC_SYS_CLKSOURCE_PLL);
    while(LL_RCC_GetSysClkSource() != LL_RCC_SYS_CLKSOURCE_STATUS_PLL);
    
    // Configure AHB and APB prescalers
    LL_RCC_SetAHBPrescaler(LL_RCC_SYSCLK_DIV_1);   // 48MHz
    LL_RCC_SetAPB1Prescaler(LL_RCC_APB1_DIV_1);    // 48MHz
    
    // Update system core clock variable
    LL_SetSystemCoreClock(48000000);
}

void I2C1_Init(void)
{
    // Enable GPIO and I2C clocks
    LL_AHB1_GRP1_EnableClock(LL_AHB1_GRP1_PERIPH_GPIOB);
    LL_APB1_GRP1_EnableClock(LL_APB1_GRP1_PERIPH_I2C1);
    
    // Configure GPIO pins for I2C1
    // PB6 -> I2C1_SCL, PB7 -> I2C1_SDA
    LL_GPIO_InitTypeDef GPIO_InitStruct = {0};
    GPIO_InitStruct.Pin = LL_GPIO_PIN_6 | LL_GPIO_PIN_7;
    GPIO_InitStruct.Mode = LL_GPIO_MODE_ALTERNATE;
    GPIO_InitStruct.Speed = LL_GPIO_SPEED_FREQ_HIGH;
    GPIO_InitStruct.OutputType = LL_GPIO_OUTPUT_OPENDRAIN;
    GPIO_InitStruct.Pull = LL_GPIO_PULL_UP;
    GPIO_InitStruct.Alternate = LL_GPIO_AF_1;
    LL_GPIO_Init(GPIOB, &GPIO_InitStruct);
    
    // Configure I2C1
    LL_I2C_InitTypeDef I2C_InitStruct = {0};
    I2C_InitStruct.PeripheralMode = LL_I2C_MODE_I2C;
    I2C_InitStruct.Timing = 0x2000090E;  // 100kHz timing for 48MHz PCLK
    I2C_InitStruct.AnalogFilter = LL_I2C_ANALOGFILTER_ENABLE;
    I2C_InitStruct.DigitalFilter = 0;
    I2C_InitStruct.OwnAddress1 = 0;
    I2C_InitStruct.TypeAcknowledge = LL_I2C_ACK;
    I2C_InitStruct.OwnAddrSize = LL_I2C_OWNADDRESS1_7BIT;
    LL_I2C_Init(I2C1, &I2C_InitStruct);
    
    // Enable I2C1
    LL_I2C_Enable(I2C1);
}

void PCA9685_SetAllServos(uint16_t angle_deg)
{
    // Set all 6 servos to the same angle
    for(uint8_t servo = 0; servo < 6; servo++)
    {
        PCA9685_SetServoAngle(servo, angle_deg);
    }
}

void PCA9685_SetMultipleServos(uint16_t angles[6])
{
    // Set each servo to a different angle
    for(uint8_t servo = 0; servo < 6; servo++)
    {
        PCA9685_SetServoAngle(servo, angles[servo]);
    }
}

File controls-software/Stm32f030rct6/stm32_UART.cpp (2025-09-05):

/* STM32F030RCT6 UART Communication Code for YOLO Object Detection Data */

#include "stm32f0xx.h"
#include <stdio.h>
#include <string.h>
#include <stdlib.h>

// Function prototypes
void SystemClock_Config(void);
void UART_Init(void);
void UART_SendString(const char* str);
void UART_SendChar(char c);
char UART_ReceiveChar(void);
void UART_ReceiveString(char* buffer, uint16_t max_len);
void GPIO_Init(void);
void ParseCoordinates(const char* data, int* center_x, int* center_y, int* width, int* height);

// Global variables
char rx_buffer[100];

int main(void)
{
    // Initialize system
    SystemClock_Config();
    GPIO_Init();
    UART_Init();
    
    // Send startup message
    UART_SendString("STM32F030RCT6 Ready - Waiting for YOLO data!\r\n");
    
    int center_x, center_y, width, height;
    char display_buffer[100];
    
    while (1)
    {
        // Wait for data reception
        UART_ReceiveString(rx_buffer, sizeof(rx_buffer));
        
        // Parse the received coordinates (format: center_x,center_y,width,height)
        ParseCoordinates(rx_buffer, &center_x, &center_y, &width, &height);
        
        // Display in the requested format: C(center coordinates), (x distance, y distance)
        sprintf(display_buffer, "C(%d,%d), (%d,%d)\r\n", center_x, center_y, width, height);
        UART_SendString(display_buffer);
        
        // Clear buffer
        memset(rx_buffer, 0, sizeof(rx_buffer));
    }
}

void ParseCoordinates(const char* data, int* center_x, int* center_y, int* width, int* height)
{
    // Initialize values to 0 in case parsing fails
    *center_x = 0;
    *center_y = 0;
    *width = 0;
    *height = 0;
    
    // Create a copy of the data for parsing
    char temp_data[100];
    strncpy(temp_data, data, sizeof(temp_data) - 1);
    temp_data[sizeof(temp_data) - 1] = '\0';
    
    // Parse comma-separated values
    char* token = strtok(temp_data, ",");
    if (token != NULL) {
        *center_x = atoi(token);
        
        token = strtok(NULL, ",");
        if (token != NULL) {
            *center_y = atoi(token);
            
            token = strtok(NULL, ",");
            if (token != NULL) {
                *width = atoi(token);
                
                token = strtok(NULL, ",");
                if (token != NULL) {
                    *height = atoi(token);
                }
            }
        }
    }
}

void SystemClock_Config(void)
{
    // Enable HSI (8MHz internal oscillator)
    RCC->CR |= RCC_CR_HSION;
    while(!(RCC->CR & RCC_CR_HSIRDY));
    
    // Set HSI as system clock
    RCC->CFGR &= ~RCC_CFGR_SW;
    RCC->CFGR |= RCC_CFGR_SW_HSI;
    while((RCC->CFGR & RCC_CFGR_SWS) != RCC_CFGR_SWS_HSI);
}

void GPIO_Init(void)
{
    // Enable GPIOA clock
    RCC->AHBENR |= RCC_AHBENR_GPIOAEN;
    
    // Configure PA9 (TX) and PA10 (RX) for UART1
    // PA9 - Alternate function, push-pull
    GPIOA->MODER &= ~(GPIO_MODER_MODER9 | GPIO_MODER_MODER10);
    GPIOA->MODER |= (GPIO_MODER_MODER9_1 | GPIO_MODER_MODER10_1);
    
    // Set alternate function to AF1 (UART1) for PA9 and PA10
    GPIOA->AFR[1] &= ~(GPIO_AFRH_AFRH1 | GPIO_AFRH_AFRH2);
    GPIOA->AFR[1] |= (0x01 << GPIO_AFRH_AFRH1_Pos) | (0x01 << GPIO_AFRH_AFRH2_Pos);
    
    // Set output speed to high
    GPIOA->OSPEEDR |= (GPIO_OSPEEDER_OSPEEDR9 | GPIO_OSPEEDER_OSPEEDR10);
}

void UART_Init(void)
{
    // Enable UART1 clock
    RCC->APB2ENR |= RCC_APB2ENR_USART1EN;
    
    // Configure UART1
    // Disable UART1 first
    USART1->CR1 &= ~USART_CR1_UE;
    
    // Set baud rate to 9600 (assuming 8MHz system clock)
    // USARTDIV = 8000000 / 9600 = 833.33 ≈ 833
    USART1->BRR = 833;
    
    // Configure frame: 8 data bits, no parity, 1 stop bit
    USART1->CR1 &= ~(USART_CR1_M | USART_CR1_PCE);
    USART1->CR2 &= ~USART_CR2_STOP;
    
    // Enable transmitter and receiver
    USART1->CR1 |= (USART_CR1_TE | USART_CR1_RE);
    
    // Enable UART1
    USART1->CR1 |= USART_CR1_UE;
}

void UART_SendChar(char c)
{
    // Wait until transmit data register is empty
    while(!(USART1->ISR & USART_ISR_TXE));
    
    // Send character
    USART1->TDR = c;
    
    // Wait until transmission is complete
    while(!(USART1->ISR & USART_ISR_TC));
}

void UART_SendString(const char* str)
{
    while(*str)
    {
        UART_SendChar(*str++);
    }
}

char UART_ReceiveChar(void)
{
    // Wait until data is received
    while(!(USART1->ISR & USART_ISR_RXNE));
    
    // Return received character
    return (char)USART1->RDR;
}

void UART_ReceiveString(char* buffer, uint16_t max_len)
{
    uint16_t i = 0;
    char c;
    
    do
    {
        c = UART_ReceiveChar();
        
        if(c == '\r')
        {
            break;
        }
        else if(c == '\n')
        {
            break;
        }
        else if(c == '\b' || c == 0x7F) // Backspace or DEL
        {
            if(i > 0)
            {
                i--;
            }
        }
        else if(i < max_len - 1)
        {
            buffer[i++] = c;
        }
        
    } while(i < max_len - 1);
    
    buffer[i] = '\0'; // Null terminate
}

// Error handler
void Error_Handler(void)
{
    while(1)
    {
        // Stay here in case of error
    }
}

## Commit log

2025-08-12 Added Inventor 3D part files, including Arm assembly
    [Assembly 1 - Part 1.0002.ipt, Assembly 1 - Part 1.ipt, Assembly 1 - Part 10.0001.ipt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]
2025-08-14 Renamed folder to CAD
    [Assembly 1 - Part 1.0002.ipt, Assembly 1 - Part 1.ipt, Assembly 1 - Part 10.0001.ipt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]
2025-08-15 create a directory for CAD step files
    [Assembly 1 - Part 1.0002.ipt, Assembly 1 - Part 1.ipt, Assembly 1 - Part 10.0001.ipt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]
2025-08-19 Added numerical symbolic kinematics expressions and CAD stl files
2025-08-19 stl part files included
    [Assembly 1 - Part 1 - Part 1.stl, Assembly 1 - Part 10.stl, Assembly 1 - Part 11_MIR - Part 1.stl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]
2025-08-19 stl exports for 3D printing
    [Assembly 1 - Part 1 - Part 1.stl, Assembly 1 - Part 10.stl, Assembly 1 - Part 11_MIR - Part 1.stl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]
2025-09-05 Added stm32 servo control, UART communication files, and python Object detection with UART communication
2025-09-24 kinematic diagram of manipulator
2025-09-27 creating kinematic diagram for manipulator
2025-09-27 update kinematic diagram
2025-09-27 update on inverse kinematics
2025-09-28 update on kinematic diagram
2025-09-29 base platform files
    [Assembly 1 - Part 1 - Part 1.stl, Assembly 1 - Part 10.stl, Assembly 1 - Part 11_MIR - Part 1.stl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]
2025-09-29 update on grid sheet prints
2025-10-01 update to kinematic diagram
2025-10-01 update to kinematics
2025-10-02 update on kinematics diagram
